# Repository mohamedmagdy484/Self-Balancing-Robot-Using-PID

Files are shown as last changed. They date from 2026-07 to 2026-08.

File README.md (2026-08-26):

# 🤖 Two-Wheeled Self-Balancing Robot (ESP32 + Custom PCB)









An end-to-end mechatronics and control systems project featuring an inverted pendulum **Self-Balancing Robot**. The system utilizes a custom-designed **100x70 mm 2-Layer PCB**, high-speed **ESP32 control loop**, **MPU6050 6-axis IMU**, and dual stepper motor drivers to maintain real-time dynamic balance via PID feedback control.

---

## 📸 Final Hardware Overview

<p align="center">

Final_Product

  <br>

  <i><b>Figure 1:</b> Assembled Custom Control Board matched against the Altium Designer 3D Model.</i>

</p>

---

## 🎥 Video Demonstration

Check out Phase 1 in action (Self-Balancing Mode & Dynamic Stability Test):

https://github.com/user-attachments/assets/dce35a30-ec2d-499b-bb23-894720cfa175

* 📹 **[Watch Demonstration Video on Google Drive](https://drive.google.com/drive/folders/1tvHIlpAVQ2EQqLJnxOTqIaO8B6XP8_57?usp=sharing)**

---

## 📌 Table of Contents

1. [Project Highlights](#-project-highlights)

2. [Technical Specifications](#-technical-specifications)

3. [Development & Hardware Evolution](#-development--hardware-evolution)

   - [Phase 1: Breadboard Prototyping](#1-breadboard-prototyping)

   - [Phase 2: Altium PCB Design & Routing](#2-altium-pcb-design--3d-modeling)

   - [Phase 3: PCB Fabrication & Assembly](#3-fabrication--assembly)

4. [Hardware Component Breakdown](#-hardware-component-breakdown)

5. [Future Enhancements (Phase 2)](#-future-enhancements-phase-2)

6. [The Engineering Team](#-the-engineering-team)

---

## ⚡ Project Highlights

* **High-Speed Control Loop:** Powered by the dual-core **ESP32** running at 240 MHz for fast PID calculation and precise step generation.

* **Noise Isolation & Decoupling:** Heavy onboard electrolytic decoupling capacitors and ground planes to suppress high-current motor switching noise.

* **System Protection:** Integrated 5x20mm glass inline fuse holder (`BLX-A`) and reverse polarity protection logic.

* **Modular Interface:** Onboard OLED screen header for interactive UI, real-time telemetry, and status feedback.

* **Custom Silkscreen Design:** Custom signature branding engraved directly onto the bottom copper/silk layer.

---

## 🛠️ Technical Specifications

| Parameter | Specification |

| :--- | :--- |

| **Main Controller** | ESP32-WROOM-32 (30-Pin Dev Module) |

| **Sensor (IMU)** | MPU6050 (3-Axis Accelerometer + 3-Axis Gyroscope) |

| **Motor Drivers** | Dual A4988 / DRV8825 Stepper Drivers with Aluminium Heatsinks |

| **Actuators** | 2x NEMA 17 Stepper Motors |

| **Board Dimensions** | 100 mm x 70 mm (Double Layer FR4) |

| **Power Source** | 3x 18650 Li-ion Battery Pack (~11.1V - 12.6V Nominal) |

| **Display Header** | 4-Pin I2C Header for 0.96" OLED Display |

| **CAD Software** | Altium Designer v25 |

---

## 🔬 Development & Hardware Evolution

### 1. Breadboard Prototyping

Initial verification of the MPU6050 complementary/Kalman filter, ESP32 timer interrupts, and stepper driver signals was executed on a breadboard.

<p align="center">

Bread_Board

  <br>

  <i><b>Figure 2:</b> Initial proof-of-concept setup testing power distribution and sensor reading.</i>

</p>

---

### 2. Altium PCB Design & 3D Modeling

To eliminate jumper wire resistance, loose contacts, and signal noise, a dedicated 100x70 mm PCB was designed in **Altium Designer**.

<p align="center">

3D_ISO



</p>

<p align="center">

  <i><b>Figure 3 & 4:</b> 3D Isometric View and 3D Top Render in Altium Designer.</i>

</p>

#### Custom Silk & Routing Layout

<p align="center">

3D_BACK

All_Layers

="686" alt="Top_Layer" src="https://github.com/user-attachments/assets/e039e3d2-e3bd-46b2-b22a-b3e5c1d8f7d8" />

  Bottom_Layer

</p>

<p align="center">

  <i><b>Figure 5, 6 & 7:</b> Bottom Silkscreen with team signatures (Left), 2D Top Layer Routing (Center), Composite Layer View with dimensions (Right).</i>

</p>

<p align="center">

No_3d

  <br>

  <i><b>Figure 8:</b> 2D Board Footprint and Component Alignment.</i>

</p>

---

### 3. Fabrication & Assembly

The fabricated bare board was thoroughly tested for trace continuity before soldering the through-hole and SMD components.

<p align="center">

984420ef-7dd9-46e1-91b4-36250dbad386

  No_3d FABRICATION

ap

</p>

<p align="center">

  <i><b>Figure 9 & 10:</b> Bare PCB next to fully soldered PCB (Left); Fabricated board physical verification over CAD layout (Right).</i>

</p>

---

## 🔌 Hardware Component Breakdown

1. **ESP32 Development Board:** Executes high-speed control loops and calculates target stepper pulse rates.

2. **MPU6050 IMU:** Positioned near the board center to minimize angular acceleration distortion.

3. **A4988 / DRV8825 Drivers:** Equipped with individual heat sinks and decoupling capacitors (`C1`, `C2`) near power pins to suppress inductive kickback.

4. **BLX-A Fuse Protection:** Inline protection preventing overcurrent damage from motor stalls.

5. **LM7805 / Voltage Regulator:** Provides clean power step-down for logic components.

---

## 🎯 Future Enhancements (Phase 2)

- [ ] **Interactive OLED UI:** Adding dynamic status faces, battery voltage monitoring, and PID parameter tuning menus.

- [ ] **Wireless Remote Control:** Implementing ESP-NOW / Wi-Fi / Bluetooth web server control for real-time steering and motion control.

- [ ] **Adaptive PID Tuning:** Implementing online auto-tuning for varying surface friction and payload changes.

---

## 👥 The Engineering Team

| Name | Role & Responsibilities |

| :--- | :--- |

| **Mohamed Magdy** | Hardware Engineering, PCB Design (Altium) & Embedded Systems |

| **Omar Elkady** | Control Theory, PID Algorithms & Embedded Logic |

| **Mohamed Assad** | System Calibration, Sensor Fusion & Embedded Systems |

| **Wagdy Mohamed** | Mechanical CAD Design & Structure Assembly |

---

<p align="center">

  <i>Developed for the College Control Systems Course — Bridging Theory & Practical Engineering 🚀</i>

</p> 

# ⚙️ Two-Wheeled Self-Balancing Robot — Mechanical Design & Hardware






A robust, modular, multi-tier mechanical chassis engineered specifically for an inverted pendulum **Self-Balancing Robot**. Built upon dynamic stabilization principles, the chassis utilizes a vertical stacked design to elevate the Center of Gravity (CoG), optimizing real-time PID responsiveness while delivering a stable platform for embedded control electronics.

---

## 📸 Hardware & CAD Overview

<p align="center">
  SolidWorks 3D CAD Render
  Assembled Robot Hardware
  <br>
  <i><b>Figure 1:</b> SolidWorks 3D CAD Render (`8.jpeg`) matched against the assembled physical prototype (`5.jpg`).</i>
</p>

---

## 📌 Table of Contents
1. [Mechanical Highlights](#-mechanical-highlights)
2. [Technical Specifications & BOM](#-technical-specifications--bom)
3. [Design & Assembly Evolution](#-design--assembly-evolution)
   - [Phase 1: SolidWorks CAD Modeling](#1-solidworks-cad-modeling)
   - [Phase 2: Structural Framing & Assembly](#2-structural-framing--assembly)
   - [Phase 3: Actuator & Power Integration](#3-actuator--power-integration)
4. [Mechanical Component Breakdown](#-mechanical-component-breakdown)
5. [Future Enhancements](#-future-enhancements)
6. [The Engineering Team](#-the-engineering-team)

---

## ⚡ Mechanical Highlights

* **Elevated Center of Gravity (CoG):** Battery pack intentionally mounted on the top tier to increase the moment of inertia, making balance corrections smoother for the PID loop.
* **Rigid Threaded Rod Pillars:** Utilizes continuous threaded steel rods with locking hex nuts for high structural rigidity and customizable tier spacing.
* **Direct-Drive Stepper Mounts:** Dual NEMA 17 stepper motors mounted low at the chassis base to minimize unwanted vibration and provide direct torque transmission.
* **Modular Electronics Bay:** Middle plate features pre-calculated mounting hole patterns for the custom ESP32 control board and MPU6050 IMU sensor.
* **High-Traction Drive System:** Heavy-duty rubber tires coupled with precision brass shaft adapters to eliminate rotational backlash during rapid direction flips.

---

## 🛠️ Technical Specifications & BOM

| Parameter | Specification |
| :--- | :--- |
| **CAD Tool** | SolidWorks 2024 |
| **Chassis Architecture** | 3-Tier Vertical Stacked System |
| **Plate Materials** | 3D Printed PLA (3mm Thickness) |
| **Structural Frame** | 4x M4 Threaded Steel Rods with Lock Nuts |
| **Actuators** | 2x NEMA 17 Stepper Motors (1.8° Step Angle) |
| **Wheels & Tires** | 65mm High-Grip Off-Road Rubber Tires |
| **Shaft Coupling** | 5mm-to-Hex Brass Rigid Shaft Couplers |
| **Power Mounting** | Top-tier 4x 18650 Li-ion Battery Enclosure |

---

## 🔬 Design & Assembly Evolution

### 1. SolidWorks CAD Modeling
The complete assembly was designed in **SolidWorks** to verify motor clearances, weight distribution, and sensor placement before fabrication.

<p align="center">
  3D CAD Front View
  3D CAD Side View
</p>
<p align="center">
  3D CAD Perspective View
  3D CAD Detailed Perspective
  <br>
  <i><b>Figures 2, 3, 4 & 5:</b> CAD Front View (`9.jpeg`), Side View (`1.jpg`), and Perspective Renders (`3.jpg`).</i>
</p>

---

### 2. Structural Framing & Assembly
Assembly of the vertical skeleton using threaded steel rods, enabling easy height adjustments between the power, electronics, and drive tiers.

<p align="center">
  Bare Structural Skeleton
  Battery Mount Assembly
  <br>
  <i><b>Figures 6 & 7:</b> Continuous threaded rod chassis frame (`6.jpg`) and top-tier 18650 battery holder assembly (`2.jpg`).</i>
</p>

---

### 3. Actuator & Power Integration
Final mounting of NEMA 17 stepper motors, brass couplers, high-traction wheels, and PCB standoffs.

<p align="center">
  Base Drive Subsystem
  Assembled Robot Side View
  <br>
  <i><b>Figures 8 & 9:</b> Drive subsystem with NEMA 17 motors and wheels (`7.jpeg`) alongside the fully wired side view (`4.jpg`).</i>
</p>

---

## 🔌 Mechanical Component Breakdown

1. **Top Tier (Power Unit):** Holds the 18650 battery holder (`2.jpg`) at the maximum vertical position to optimize inverted pendulum physics.
2. **Middle Tier (Control Platform):** Houses the ESP32 main PCB, MPU6050 IMU, and OLED telemetry display (`5.jpg`).
3. **Bottom Tier (Drive Unit):** Direct structural housing for two NEMA 17 motors using M3 mounting fasteners (`7.jpeg`).
4. **Threaded Rod Pillars:** Continuous steel rods acting as the central load-bearing skeleton (`6.jpg`).
5. **Wheel Assemblies:** High-grip wheels locked directly onto motor shafts via brass set-screw couplers (`7.jpeg`).

---

## 🎯 Future Enhancements

- [ ] **Protective Chassis Shell:** Lightweight 3D-printed outer cover to protect electronics during fall testing.
- [ ] **Aluminum Plate Upgrade:** Replacing PLA plates with 2mm CNC aluminum for maximum durability.
- [ ] **Dampened Sensor Mount:** Adding rubber anti-vibration grommets under the MPU6050 mount to filter out high-frequency motor noise.

---

## 👥 The Engineering Team

| Name | Role & Responsibilities |
| :--- | :--- |
| **Wagdy Mohamed** | Mechanical CAD Design, Assembly & Physical Prototyping |
| **Mohamed Magdy** | PCB Engineering & Hardware Design |
| **Omar Elkady** | Control Systems & Embedded PID Logic |
| **Mohamed Assad** | Sensor Fusion & System Calibration |

---

<p align="center">
  <i>Designed & Fabricated for the Mechatronics & Control Systems Engineering Course 🚀</i>
</p>

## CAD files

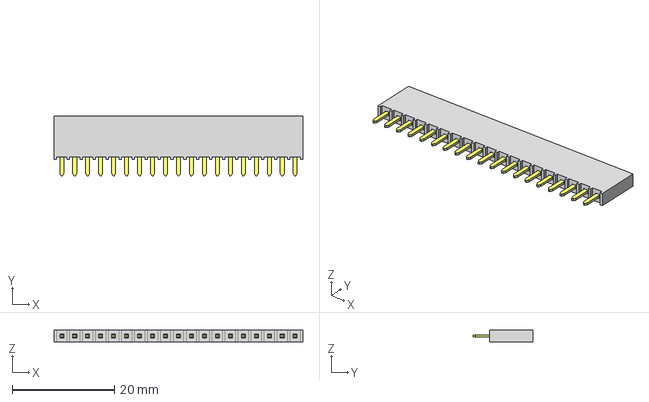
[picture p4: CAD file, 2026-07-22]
Hardware ( PCB-Design + Simulations )/COMPONENTS/19_pin_header/SSW-119-06-S-S.stp
48.8 x 11.7 x 2.41 mm
T1SSW-119-06-S-S
P2SSW-119-06-S-S

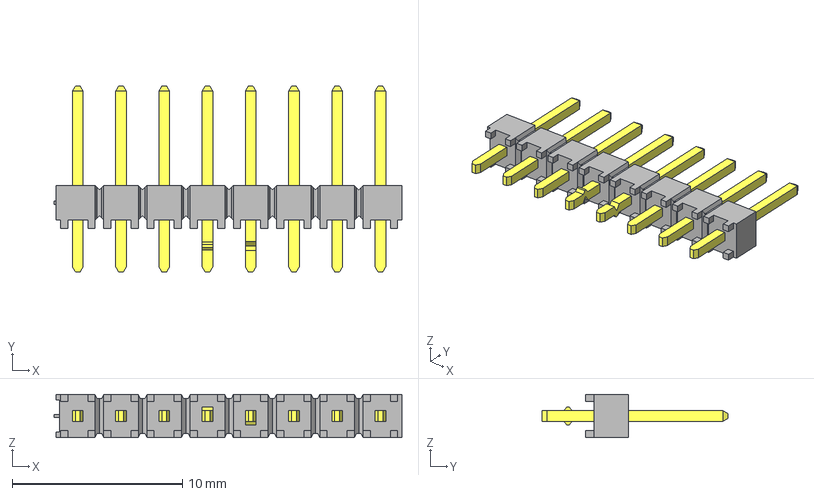
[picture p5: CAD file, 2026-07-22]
Hardware ( PCB-Design + Simulations )/COMPONENTS/8-PIN-Male/3D/TSW-108-07-G-S-LL.stp
20.4 x 10.9 x 2.54 mm
TSW-108-07-G-S-LL_body
T-1S6-07-TSW-1-07-8-S-LL

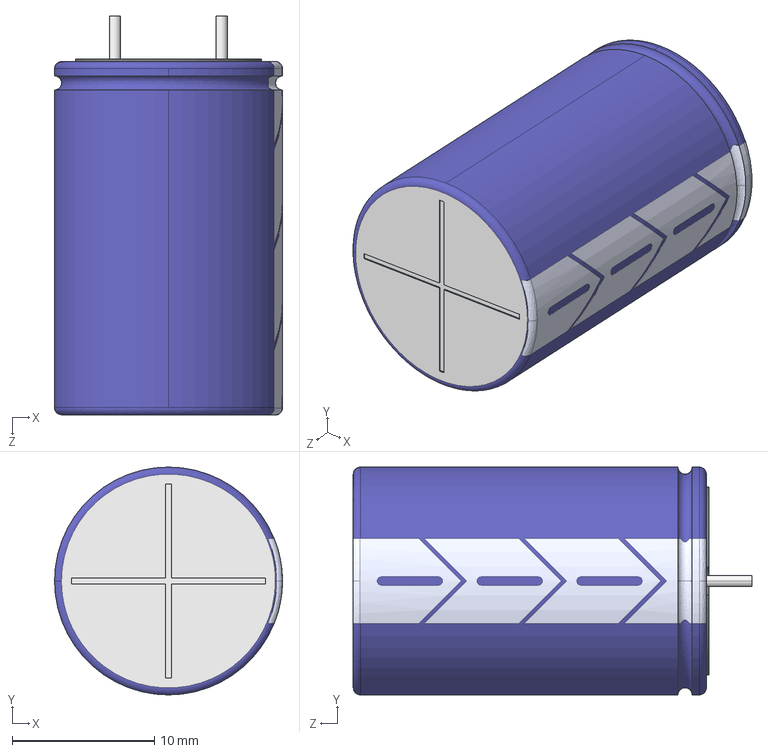
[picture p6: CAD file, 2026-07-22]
Hardware ( PCB-Design + Simulations )/COMPONENTS/Cap_edited/2200UF/User Library-CAPAER_D160_L250_P075_W008X030.STEP
16.0 x 16.0 x 28.0 mm

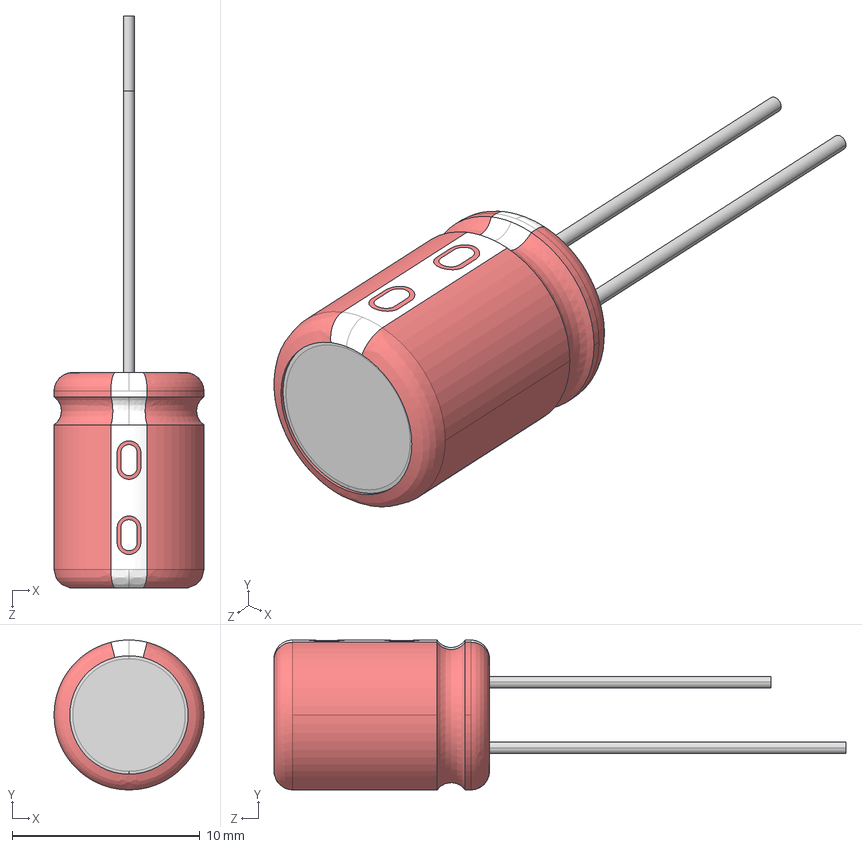
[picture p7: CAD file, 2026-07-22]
Hardware ( PCB-Design + Simulations )/COMPONENTS/Cap_edited/User Library-CAP 8X11_5.STEP
8.00 x 8.00 x 30.5 mm

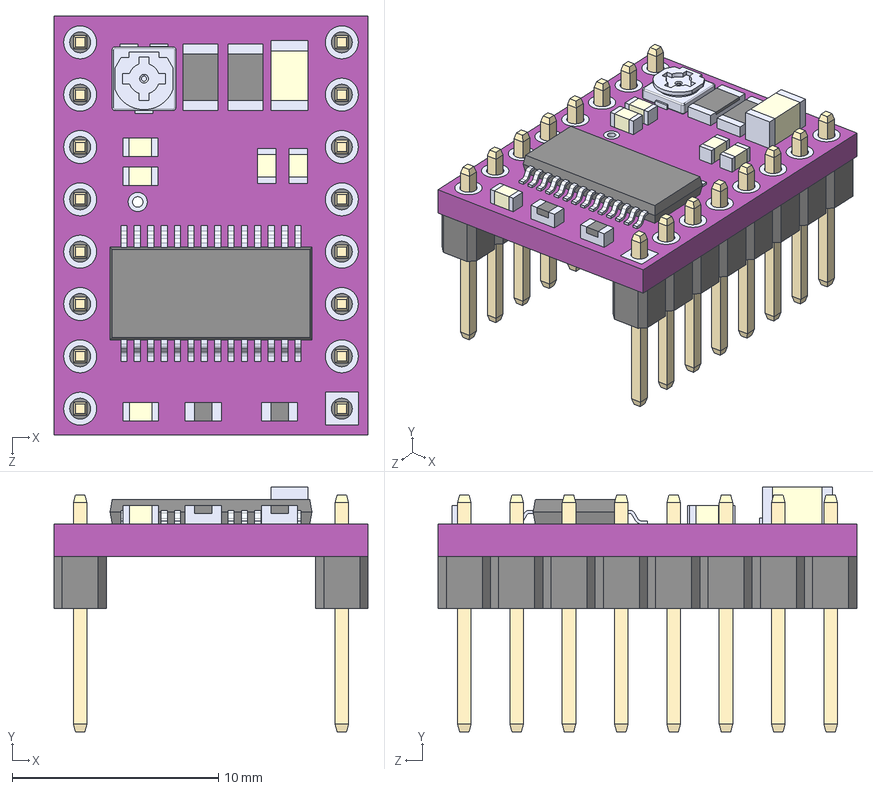
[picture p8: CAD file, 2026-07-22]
Hardware ( PCB-Design + Simulations )/COMPONENTS/DRV8825_STEPPER_MOTOR/3d-model/DRV8825 STEPPER MOTOR DRIVER CARRIER--3DModel-STEP-1.STEP
15.2 x 11.9 x 20.3 mm

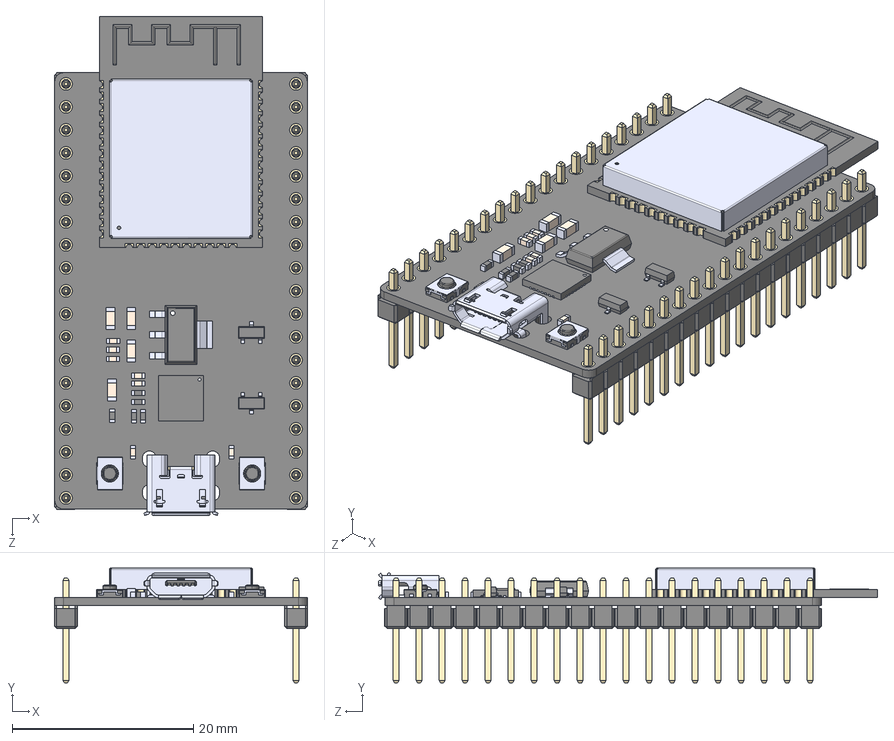
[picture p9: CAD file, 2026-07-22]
Hardware ( PCB-Design + Simulations )/COMPONENTS/esp32/ESP32-DEVKITC-32E--3DModel-STEP-269445.STEP
27.9 x 12.7 x 55.1 mm
board
header x 2
ESP32-WROOM-32D
micro usb
button x 2
CP2102N-A01-GQFN28
AMS1117-3.3
SS8050-G
components^DEVKIT V1 ESP32-WROOM-32

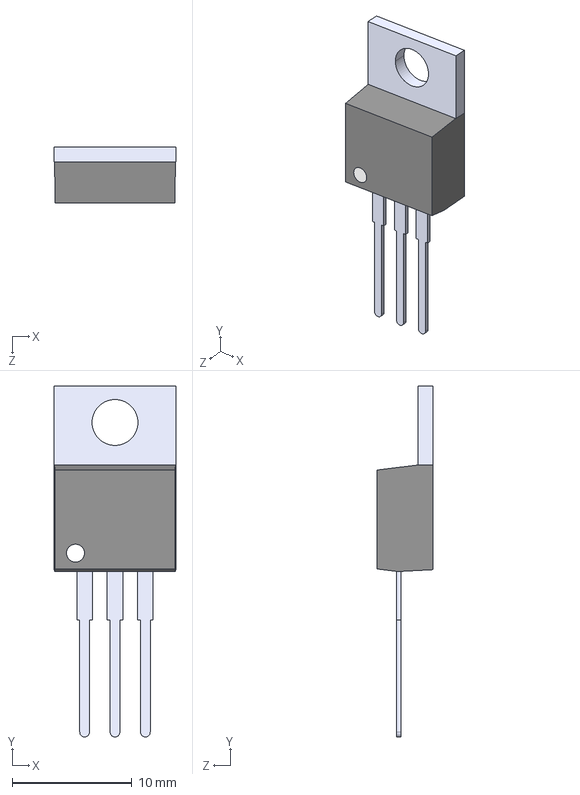
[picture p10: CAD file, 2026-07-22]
Hardware ( PCB-Design + Simulations )/COMPONENTS/LM7805/3D/LM7805CT_NOPB.STEP
10.2 x 29.3 x 4.70 mm

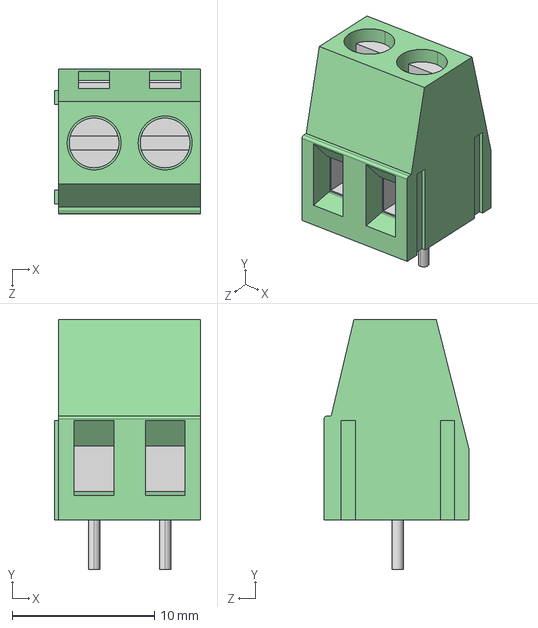
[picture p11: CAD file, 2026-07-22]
Hardware ( PCB-Design + Simulations )/COMPONENTS/PCB_POWER_CONNECTION-(ROZETA)/3D/User Library-DG128-5_0-02P-14.STEP
10.3 x 17.6 x 10.2 mm

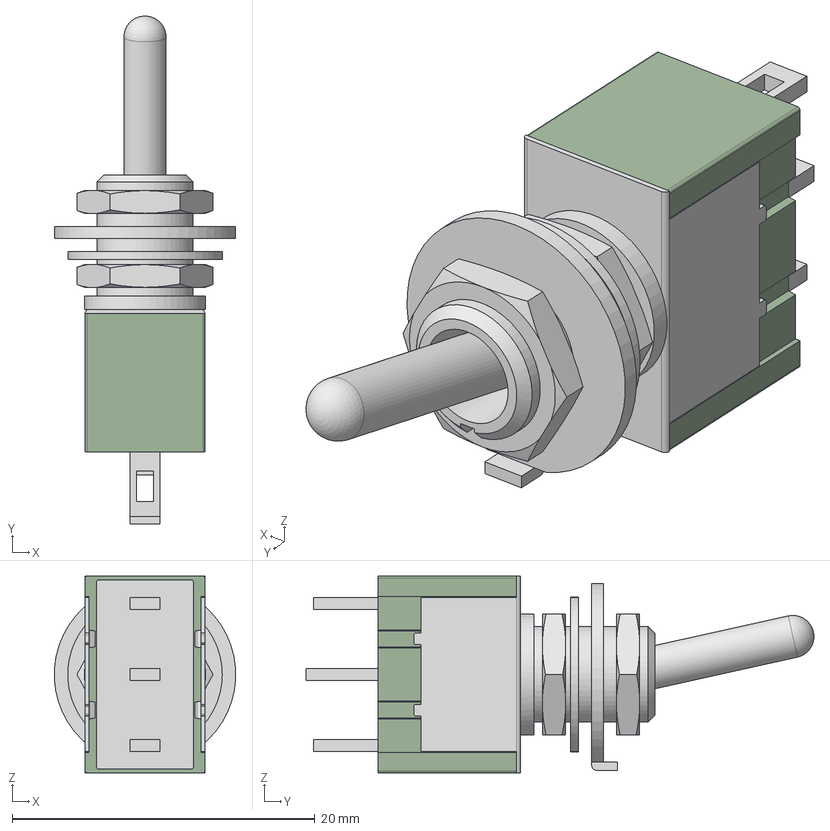
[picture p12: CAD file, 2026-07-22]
Hardware ( PCB-Design + Simulations )/COMPONENTS/Switch/3d/M2012SS1W01.stp
12.0 x 33.6 x 13.0 mm
M20121SS1W01-switch
M201S1M201-bushing
AT513H x 2
AT507H
AT509
M201201-terminals
M20S-toggles
M20S-caps

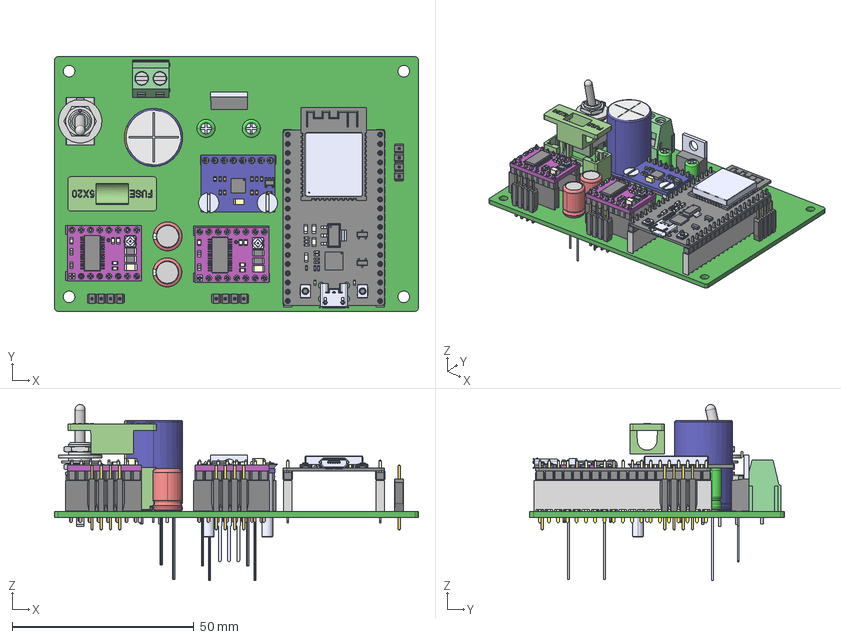
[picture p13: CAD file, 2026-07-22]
Hardware ( PCB-Design + Simulations )/PCB_3D_MODEL/PCB1.step
100.0 x 70.0 x 48.4 mm
CAPAER_D160_L250_P075_W008X030
M20121SS1W01-switch
M201S1M201-bushing
AT513H x 2
AT507H
AT509
M201201-terminals
M20S-toggles
M20S-caps
T1SSW-119-06-S-S x 2
P2SSW-119-06-S-S x 2
6130xx11821_PIN x 40
LM7805CT_NOPB
TR00011471-000 x 2
TSW-108-07-G-S-LL_body
T-1S6-07-TSW-1-07-8-S-LL
User Library-DG128-5_0-02P-14
DRV8825 STEPPER MOTOR DRIVER CARRIER--3DModel-STEP-1 x 2
board
header x 2
ESP32-WROOM-32D
micro usb
button x 2
CP2102N-A01-GQFN28
AMS1117-3.3
SS8050-G
components^DEVKIT V1 ESP32-WROOM-32

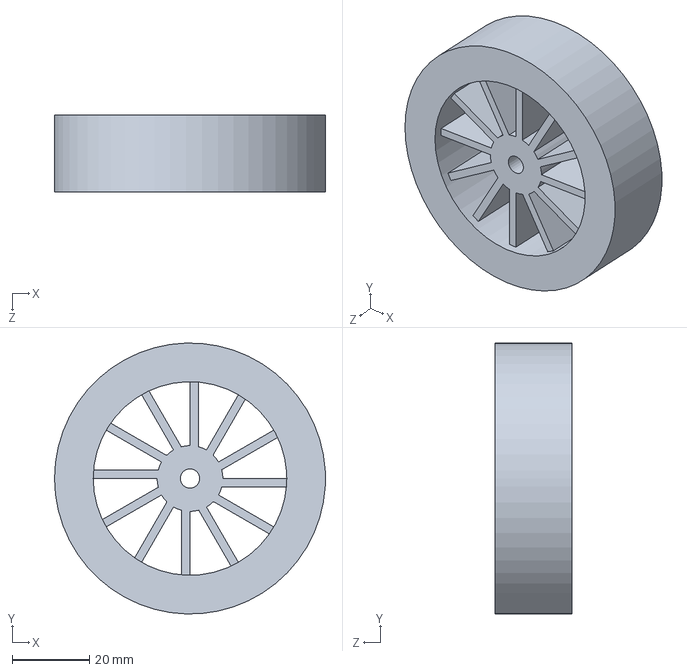
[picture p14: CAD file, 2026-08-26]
Mechanical_Design/Solid_Works_3d_Body/wheel.SLDPRT
70.0 x 70.0 x 20.0 mm

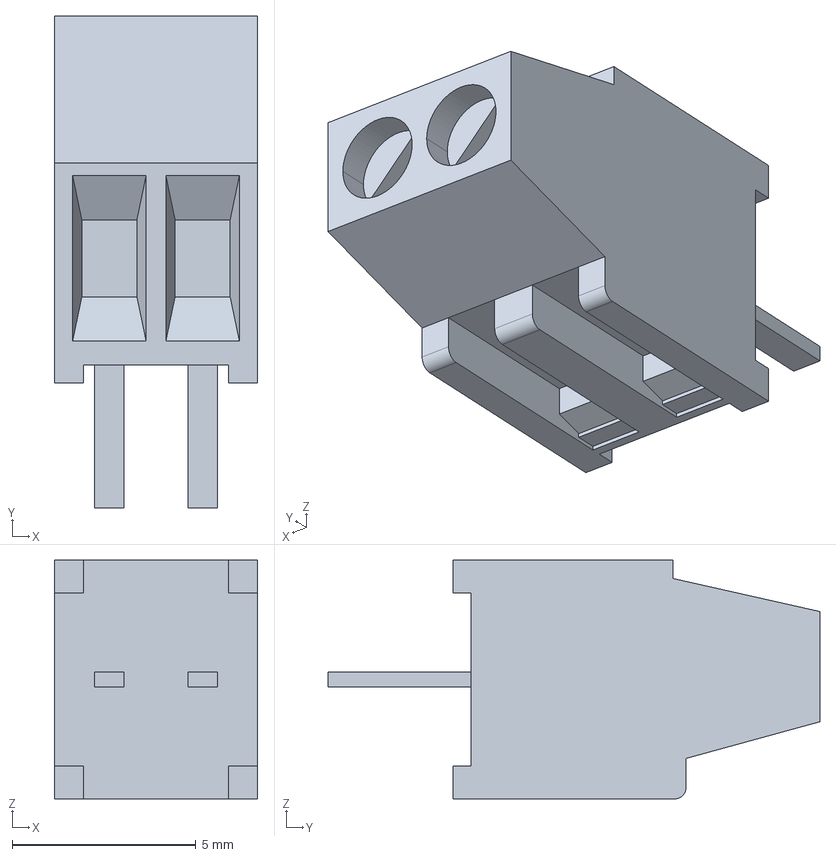
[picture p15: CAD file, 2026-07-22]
Hardware ( PCB-Design + Simulations )/COMPONENTS/PCB_POWER_CONNECTION-(ROZETA)/3D/c-282834-2-c-3d.stp
5.54 x 13.4 x 6.50 mm

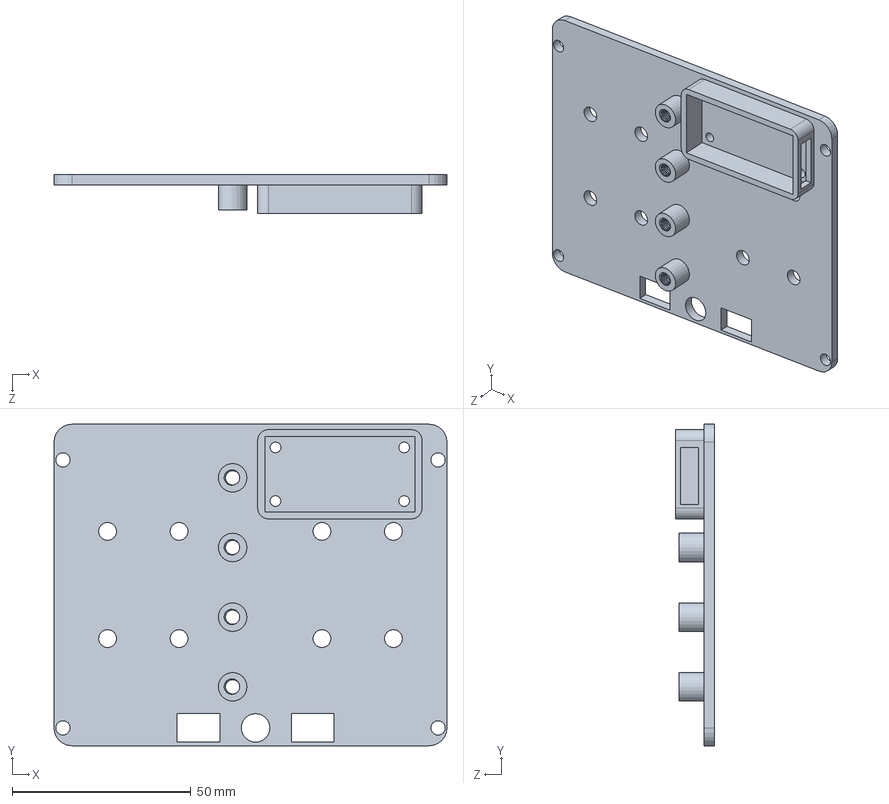
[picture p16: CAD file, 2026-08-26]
Mechanical_Design/Solid_Works_3d_Body/power control.SLDPRT
110.0 x 90.0 x 11.0 mm

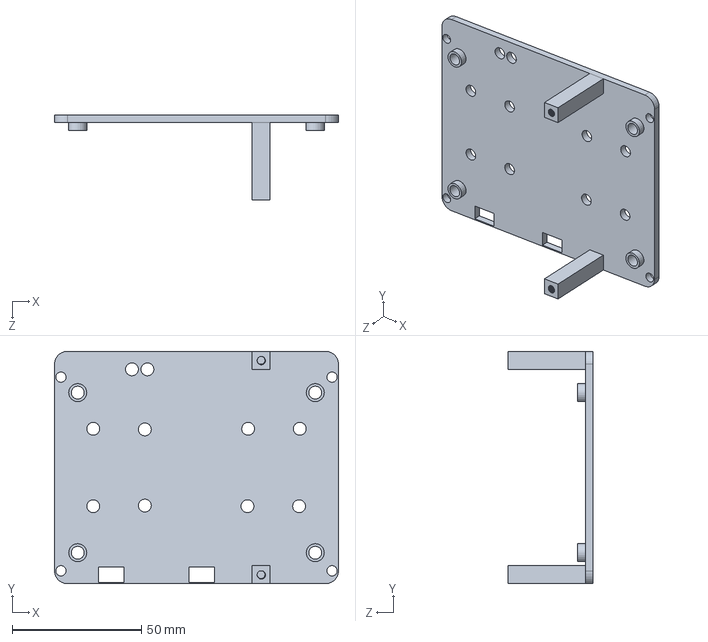
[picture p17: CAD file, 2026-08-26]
Mechanical_Design/Solid_Works_3d_Body/pcb housing.SLDPRT
110.0 x 90.0 x 33.0 mm

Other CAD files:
Mechanical_Design/Solid_Works_3d_Body/nema 17 holder.SLDPRT
Hardware ( PCB-Design + Simulations )/COMPONENTS/3M-Screw-(Mechanical)/TR00011471-000.STEP
Hardware ( PCB-Design + Simulations )/COMPONENTS/Gyroscope/3D/OC09600--3DModel-STEP-269445.STEP
Hardware ( PCB-Design + Simulations )/COMPONENTS/PCB_POWER_CONNECTION-(ROZETA)/3D/17573.stp

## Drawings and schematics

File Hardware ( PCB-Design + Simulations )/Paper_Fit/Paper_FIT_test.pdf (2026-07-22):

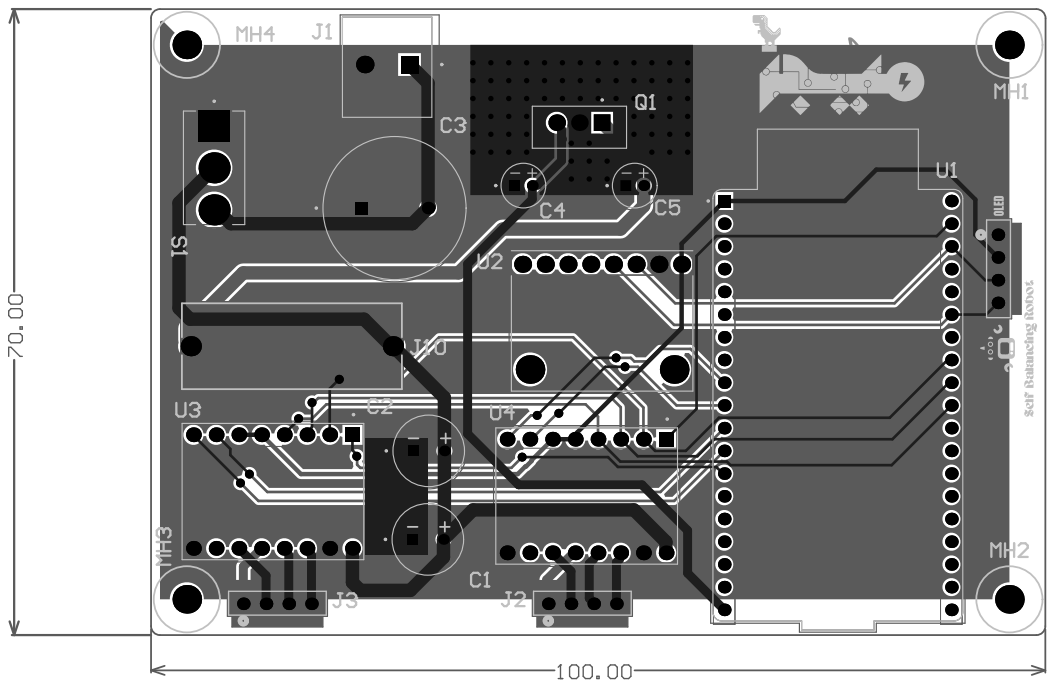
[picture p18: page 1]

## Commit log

2026-08-26 Create PCB_READ-ME
2026-08-26 Update PCB_READ-ME

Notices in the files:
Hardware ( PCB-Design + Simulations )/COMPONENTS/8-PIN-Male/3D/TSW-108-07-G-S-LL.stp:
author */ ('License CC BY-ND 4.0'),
